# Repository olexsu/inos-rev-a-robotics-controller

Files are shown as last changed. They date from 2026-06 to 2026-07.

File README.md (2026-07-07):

# INOS Rev A 

INOS Rev A is a custom robotics controller developed as a dedicated real-time motion-control node for NVIDIA Jetson-based robotic systems.

The platform follows a distributed control architecture where the NVIDIA Jetson performs high-level functions such as computer vision, AI processing, motion planning, and operator interaction, while the INOS controller executes deterministic real-time functions including motion control, homing, safety monitoring, sensor processing, and hardware management.

The first implementation of the INOS platform is a six-axis robotic arm prototype utilizing stepper motors, external motor drivers, and inductive proximity sensors for joint homing and position reference.

---

# Project Overview

INOS is built around a simple principle:

**High-level intelligence belongs on the Jetson.
Real-time control belongs on dedicated embedded hardware.**

This separation allows the robotics platform to maintain deterministic motion control while leveraging the computational capabilities of NVIDIA Jetson hardware for future AI and machine vision applications.

## NVIDIA Jetson Responsibilities

* Computer vision
* AI processing
* Motion planning
* User interface
* Task execution logic

## INOS Controller Responsibilities

* Multi-axis motion control
* Homing routines
* Safety monitoring
* Sensor processing
* CAN communication
* Hardware management

---

# Hardware Features

* Teensy 4.1 real-time controller
* CAN bus communication with NVIDIA Jetson
* 24V industrial power architecture
* Six-axis robotic arm support
* External STEP/DIR motor driver architecture
* Inductive proximity sensor integration
* Joint homing and position reference system
* Custom 4-layer PCB designed in KiCad
* Modular expansion architecture

---

# System Architecture

```text
Controller / Vision System
            │
            ▼
     NVIDIA Jetson
   (High-Level Control)
            │
         CAN Bus
            │
            ▼
        INOS Rev A
 (Real-Time Controller)
            │
        STEP / DIR
            │
            ▼
 External Driver Board
            │
            ▼
     Stepper Motors
            │
            ▼
 Inductive Homing Sensors
```

---

# Homing and Position Reference

One of the core functions of INOS Rev A is establishing known joint positions after power-up.

Because stepper motors do not inherently know their absolute position when the system starts, each robotic axis uses an inductive proximity sensor as a mechanical reference point.

During initialization:

1. The controller moves each joint toward its reference position.
2. The inductive sensor detects the target.
3. The controller records the reference position.
4. The robot establishes a known coordinate system for all subsequent motion.

This homing architecture allows repeatable positioning and forms the foundation for future inverse kinematics, trajectory planning, and autonomous operation.

---

# Custom Controller Hardware

## Partly Assembled Controller Board — Top

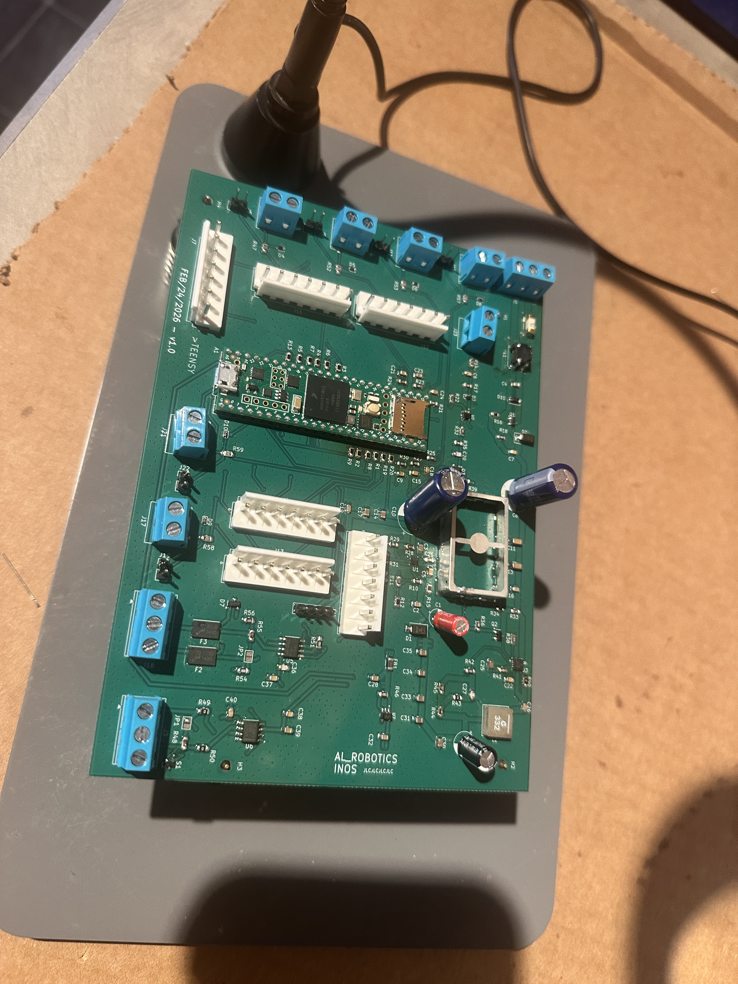
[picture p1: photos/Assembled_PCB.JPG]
INOS Rev A Board Bottom


Features:

* Custom 4-layer PCB
* Teensy 4.1 controller
* CAN transceiver
* Sensor interfaces
* Motion-control interfaces
* 24V power architecture
* Expansion capability

---

# PCB Design

## 3D Render

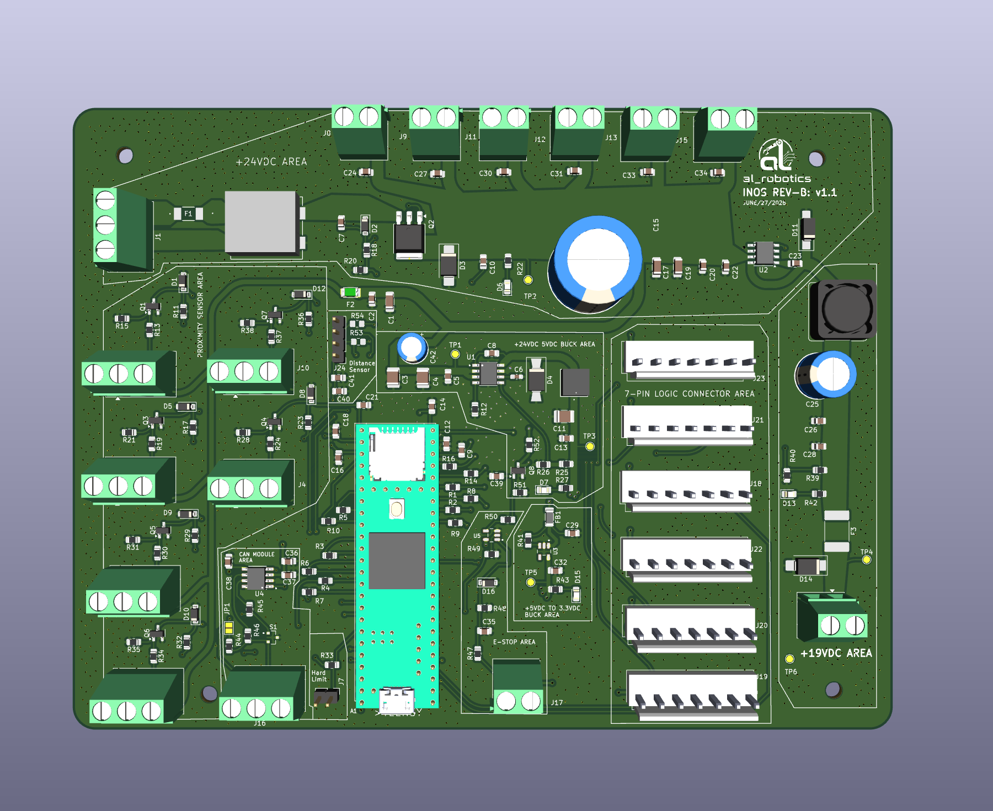
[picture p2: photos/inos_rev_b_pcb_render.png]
3D Render


Designed using KiCad and manufactured through JLCPCB.

---

# Development and Validation

## Power-On Testing

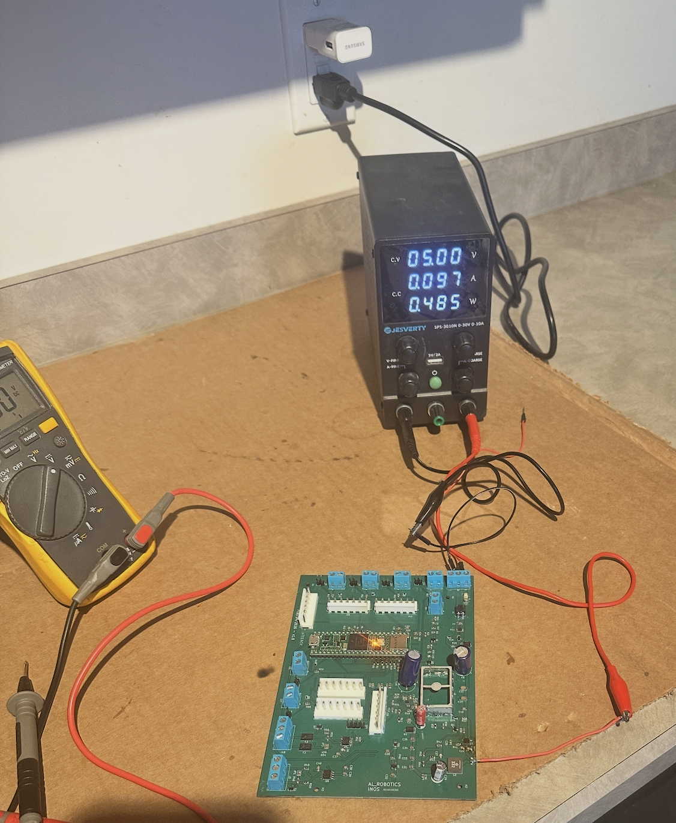
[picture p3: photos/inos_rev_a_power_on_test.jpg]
Power-On Testing


## CAN Communication Testing

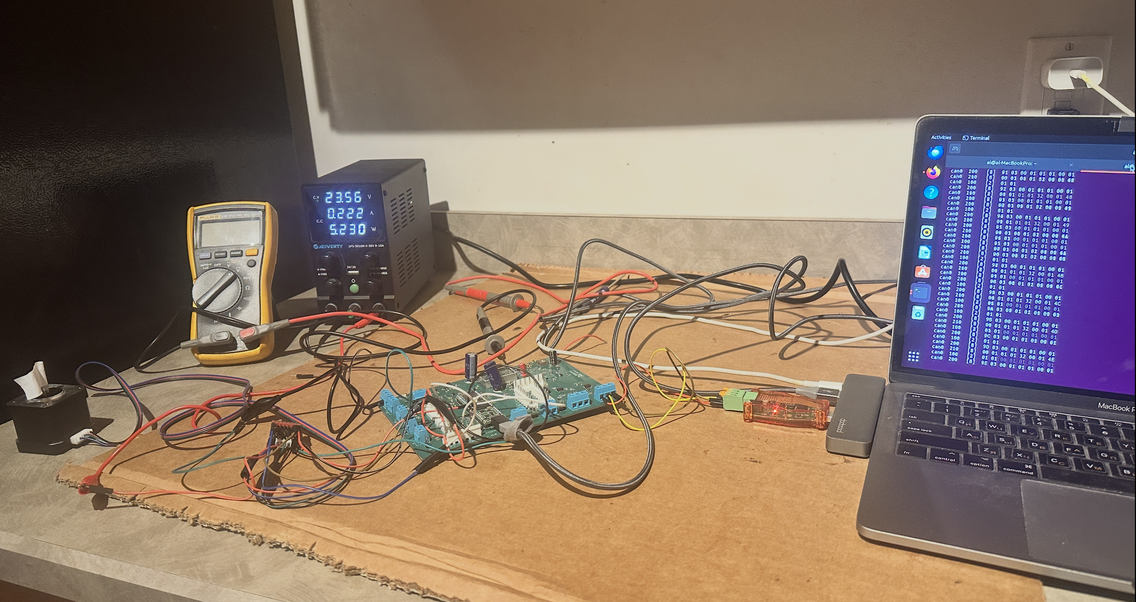
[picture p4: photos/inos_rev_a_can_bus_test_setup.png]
CAN Bus Testing


The INOS Rev A platform has successfully demonstrated:

* Controller board bring-up
* CAN communication
* Multi-axis motion control
* Inductive sensor integration
* Joint homing
* Robotic arm operation
* Embedded firmware validation

---

# Current Status

## Completed

* Custom PCB design
* PCB manufacturing and assembly
* Teensy 4.1 integration
* CAN communication testing
* Multi-axis motion control
* Inductive homing implementation
* Robotic arm prototype integration

## In Progress

* Motion-control refinement
* Safety system development
* CAN protocol expansion
* System optimization

## Planned

* NVIDIA Jetson integration
* Computer vision
* Inverse kinematics
* Autonomous operation
* Agricultural robotics applications

---

# Project Goals

The long-term objective of the INOS platform is to create a scalable robotics architecture capable of supporting:

* Robotic manipulators
* Agricultural automation systems
* Machine vision platforms
* Autonomous robotic applications
* Custom embedded robotics solutions

---

# Development Tools

* KiCad
* Teensy 4.1
* C++
* FlexCAN_T4
* NVIDIA Jetson
* Ubuntu Linux
* GitHub
* JLCPCB

---

# Disclaimer

INOS Rev A is an experimental development platform and active engineering project. The hardware and software are continuously evolving as new features, capabilities, and lessons learned are incorporated into future revisions.

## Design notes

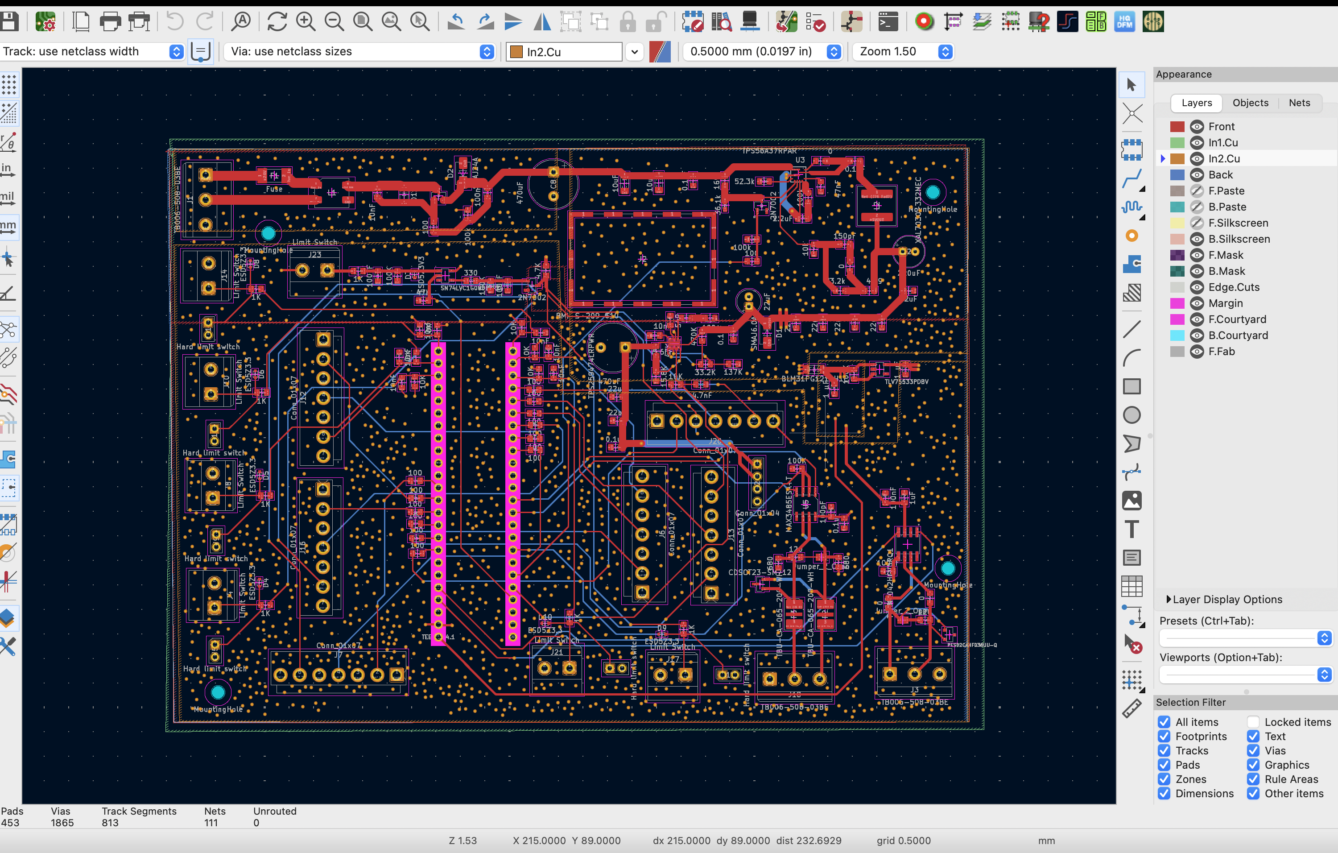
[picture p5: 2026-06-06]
photos/inos_rev_a_pcb_layout.png

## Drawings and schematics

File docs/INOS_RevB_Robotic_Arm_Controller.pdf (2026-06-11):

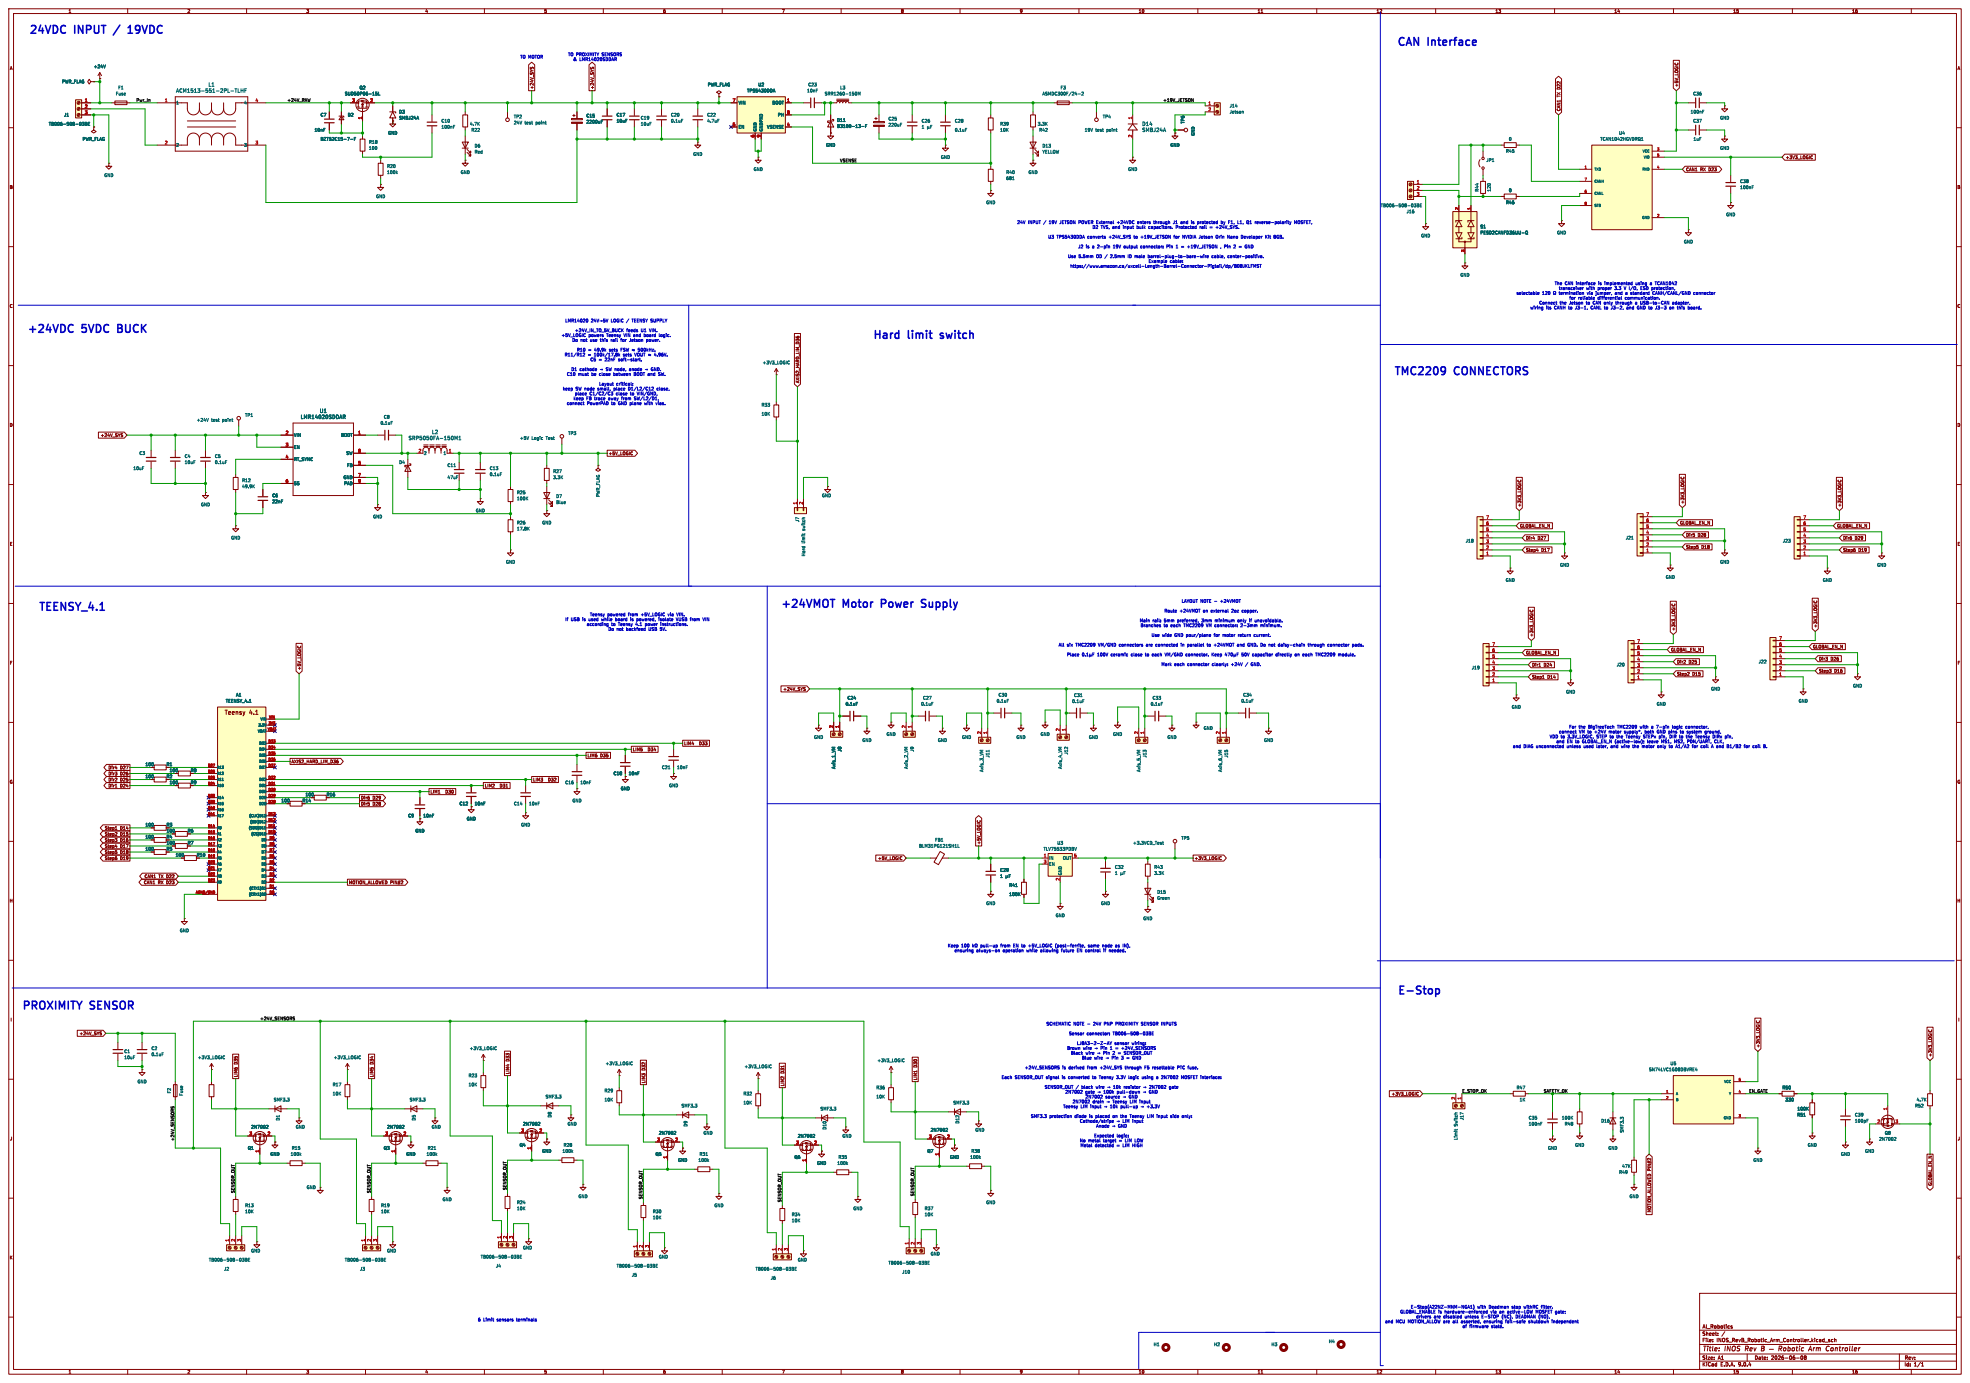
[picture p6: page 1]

Example cable: https://www.amazon.ca/uxcell-Length-Barrel-Connector-Pigtail/dp/B08JKLFMST

LMR14020 þÿ24V!’5VLOGIC / TEENSY SUPPLY

Teensy powered from +5V_LOGIC via VIN.

If USB is used while board is powered, isolate VUSB from VIN

SCHEMATIC NOTE - 24V PNP PROXIMITY SENSOR INPUTS

Black wire þÿ!’Pin 2 = SENSOR_OUT Blue wire þÿ!’Pin 3 = GND

2N7002 source þÿ!’GND
2N7002 drain þÿ!’Teensy LIM input

Expected logic: No metal target = LIM LOW

Id: 1/1 Title: INOS Rev B þÿ Robotic Arm Controller File: INOS_RevB_Robotic_Arm_Controller.kicad_sch Sheet: / Al_Robotics

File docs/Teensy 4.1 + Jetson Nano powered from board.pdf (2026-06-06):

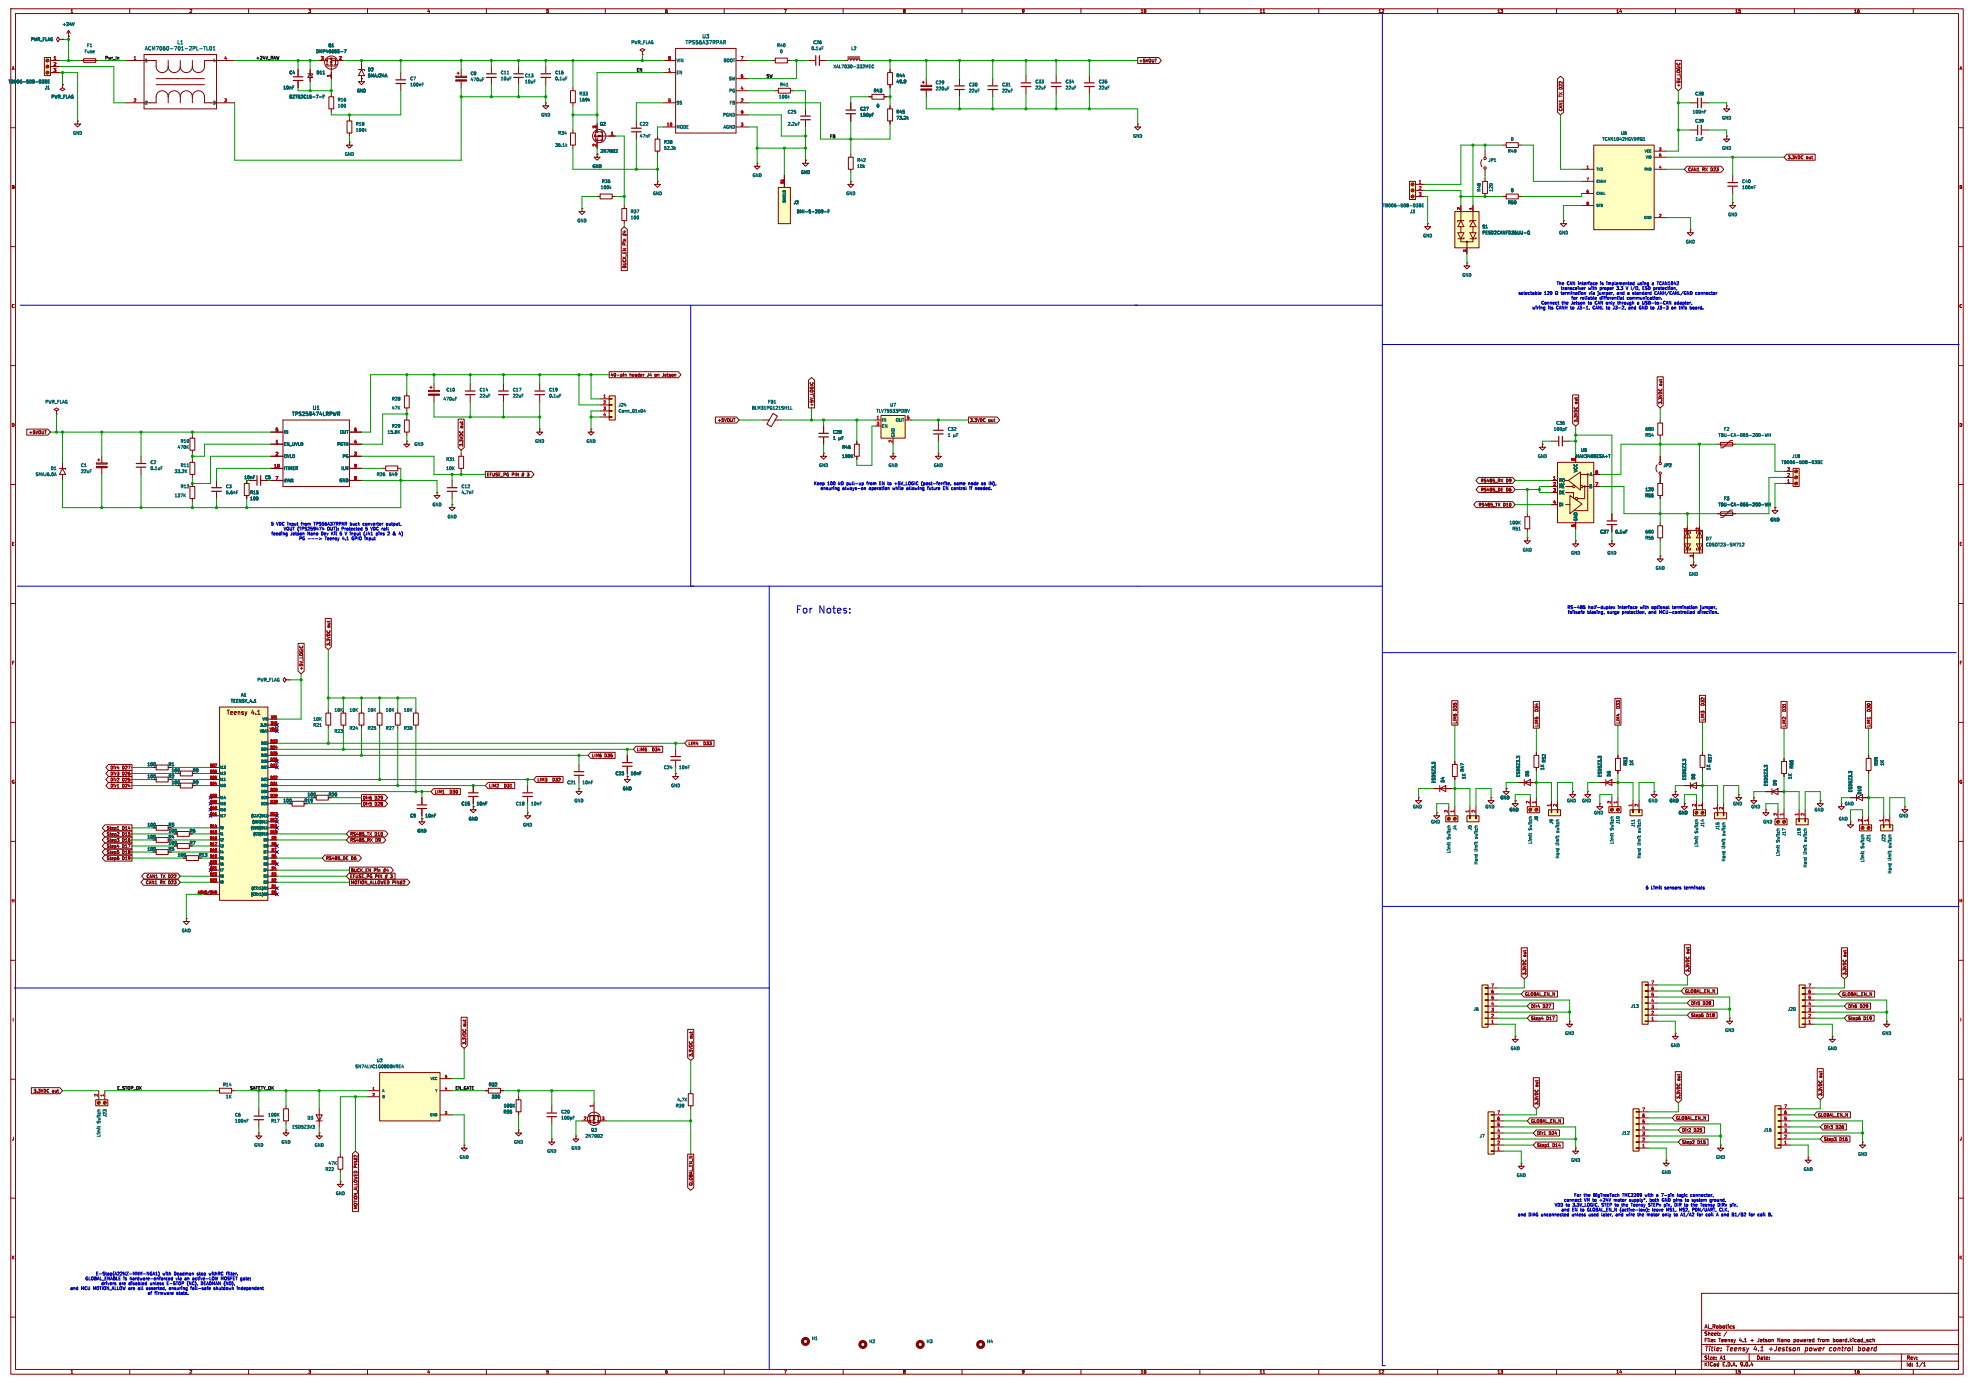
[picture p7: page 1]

1 J17 Limit Switch F3 TBU-CA-065-200-WH

Id: 1/1 Title: Teensy 4.1 +Jestson power control board

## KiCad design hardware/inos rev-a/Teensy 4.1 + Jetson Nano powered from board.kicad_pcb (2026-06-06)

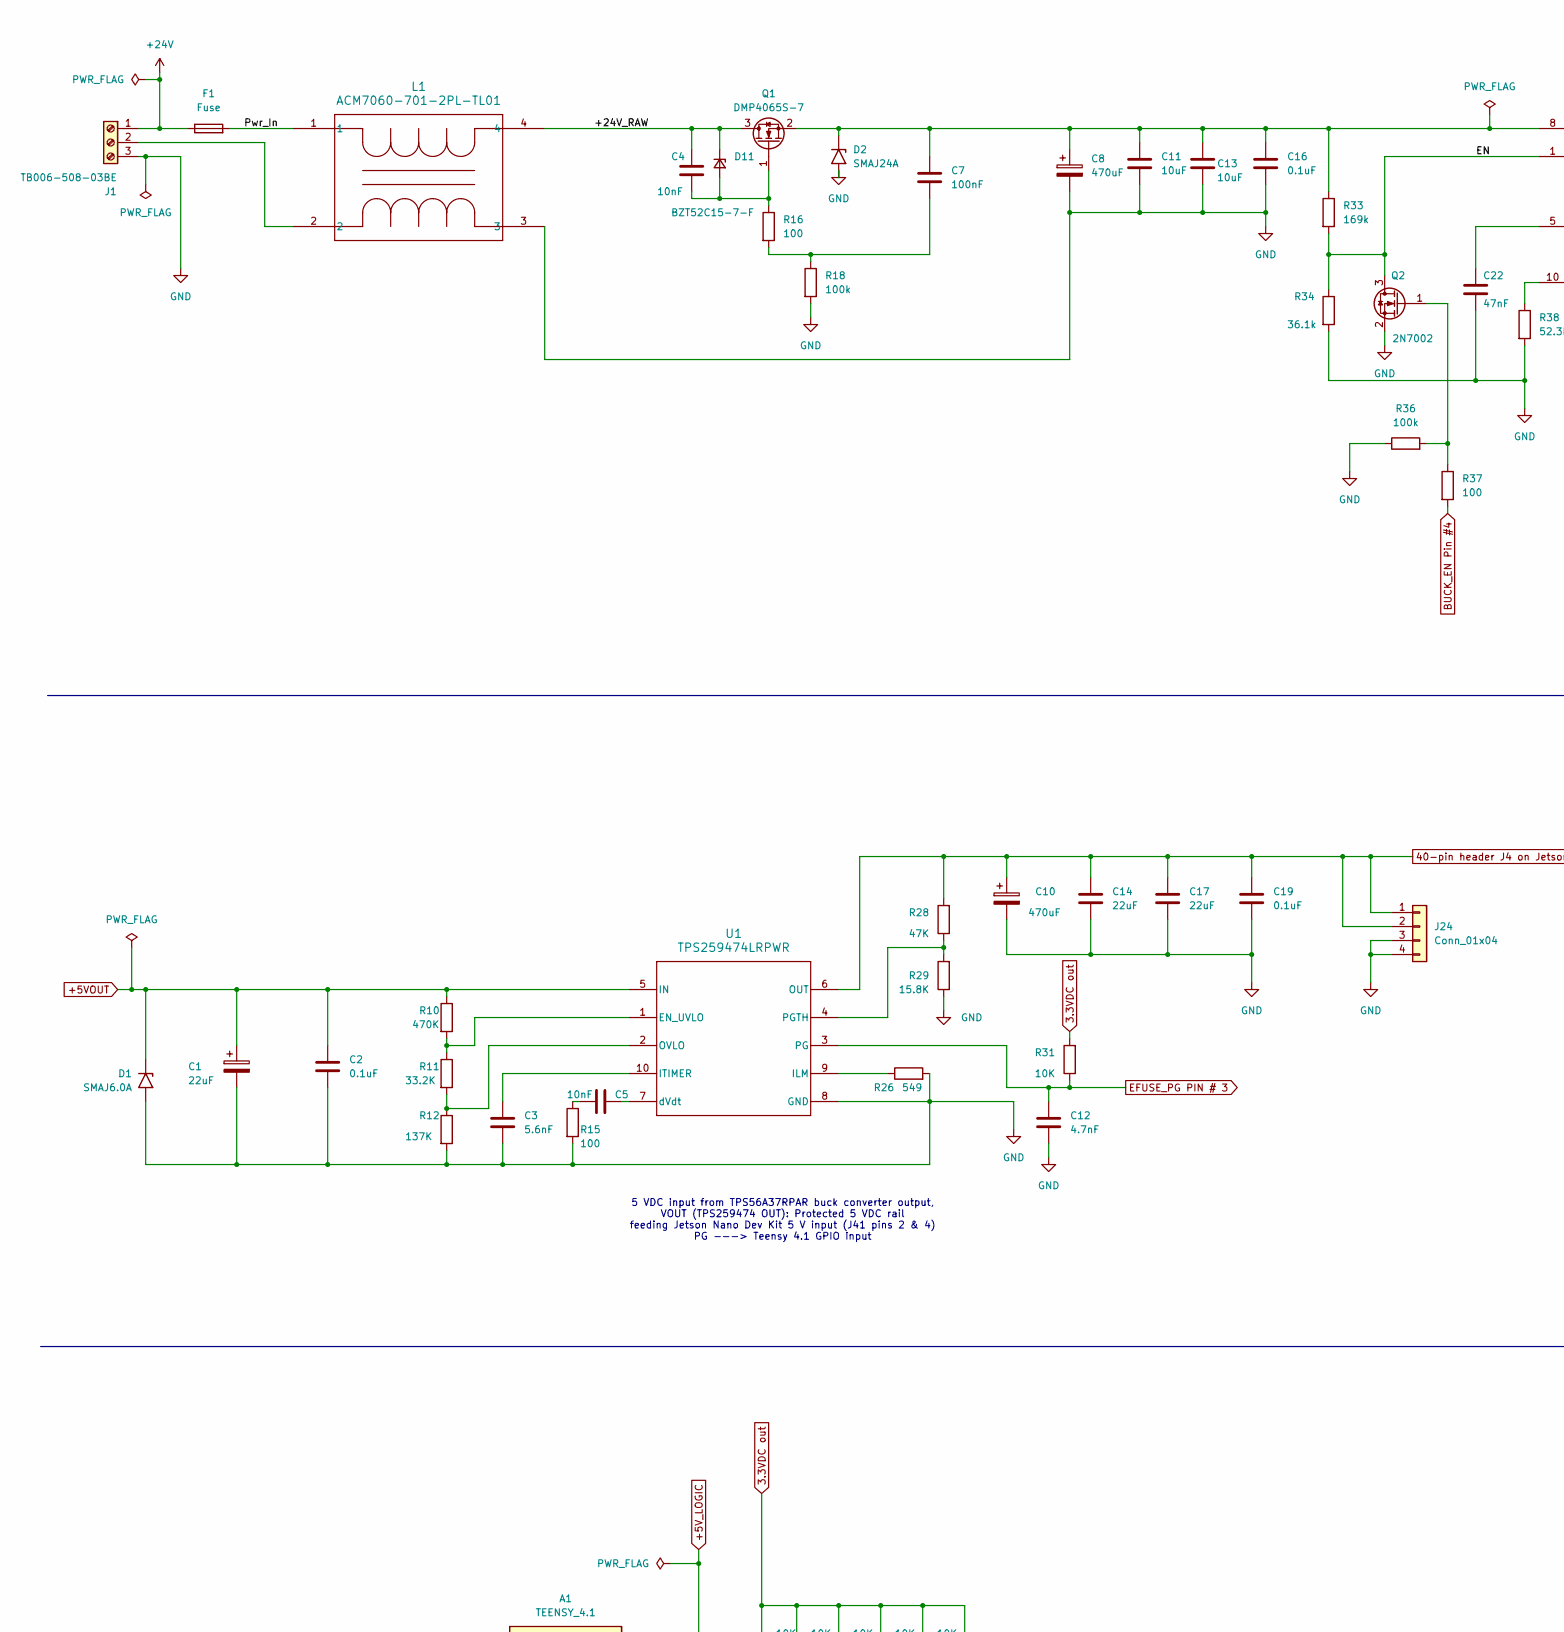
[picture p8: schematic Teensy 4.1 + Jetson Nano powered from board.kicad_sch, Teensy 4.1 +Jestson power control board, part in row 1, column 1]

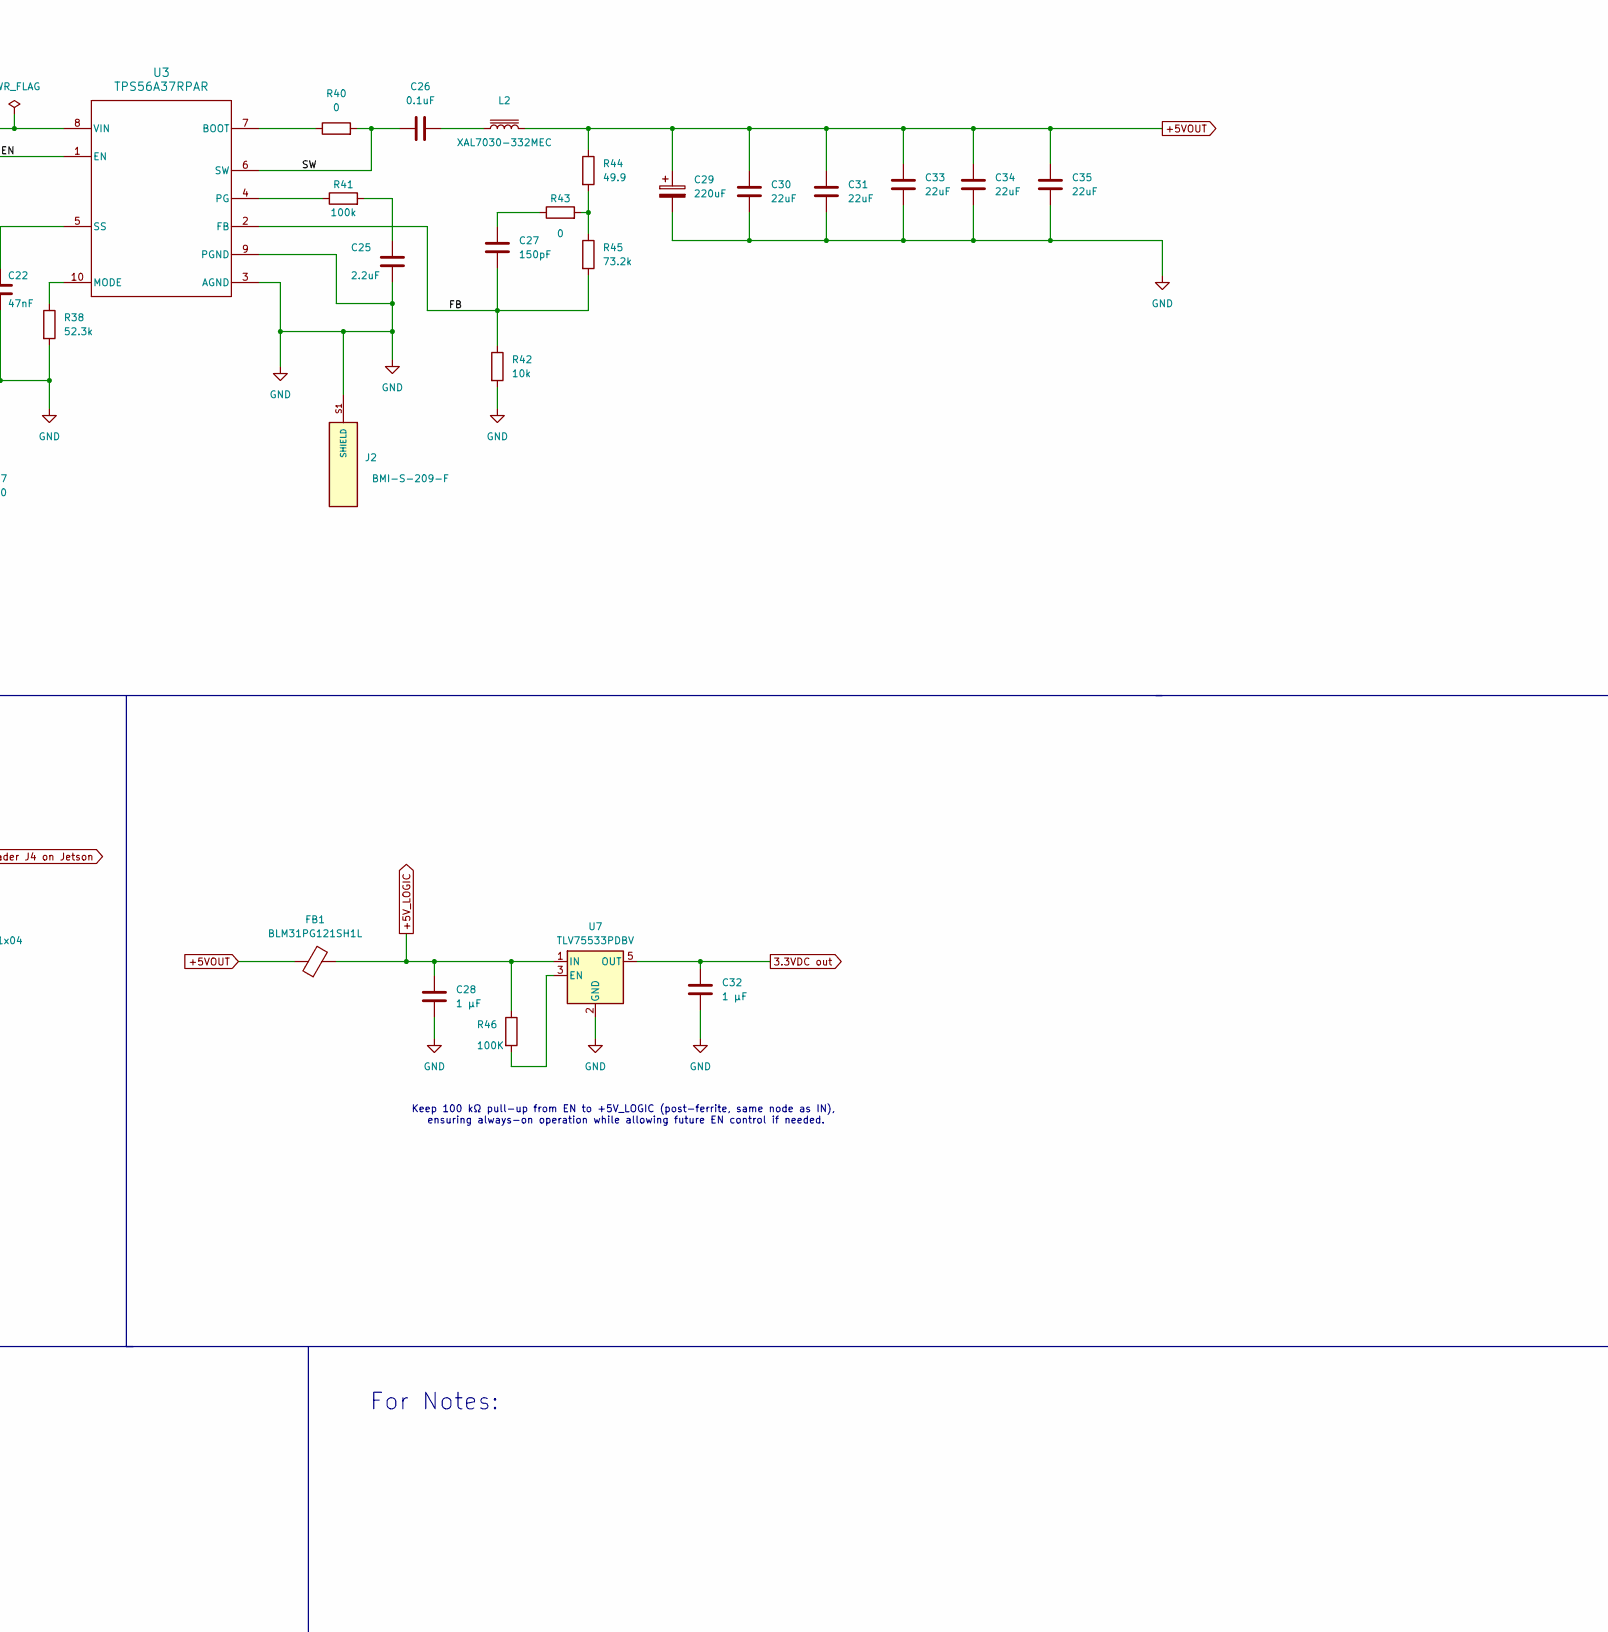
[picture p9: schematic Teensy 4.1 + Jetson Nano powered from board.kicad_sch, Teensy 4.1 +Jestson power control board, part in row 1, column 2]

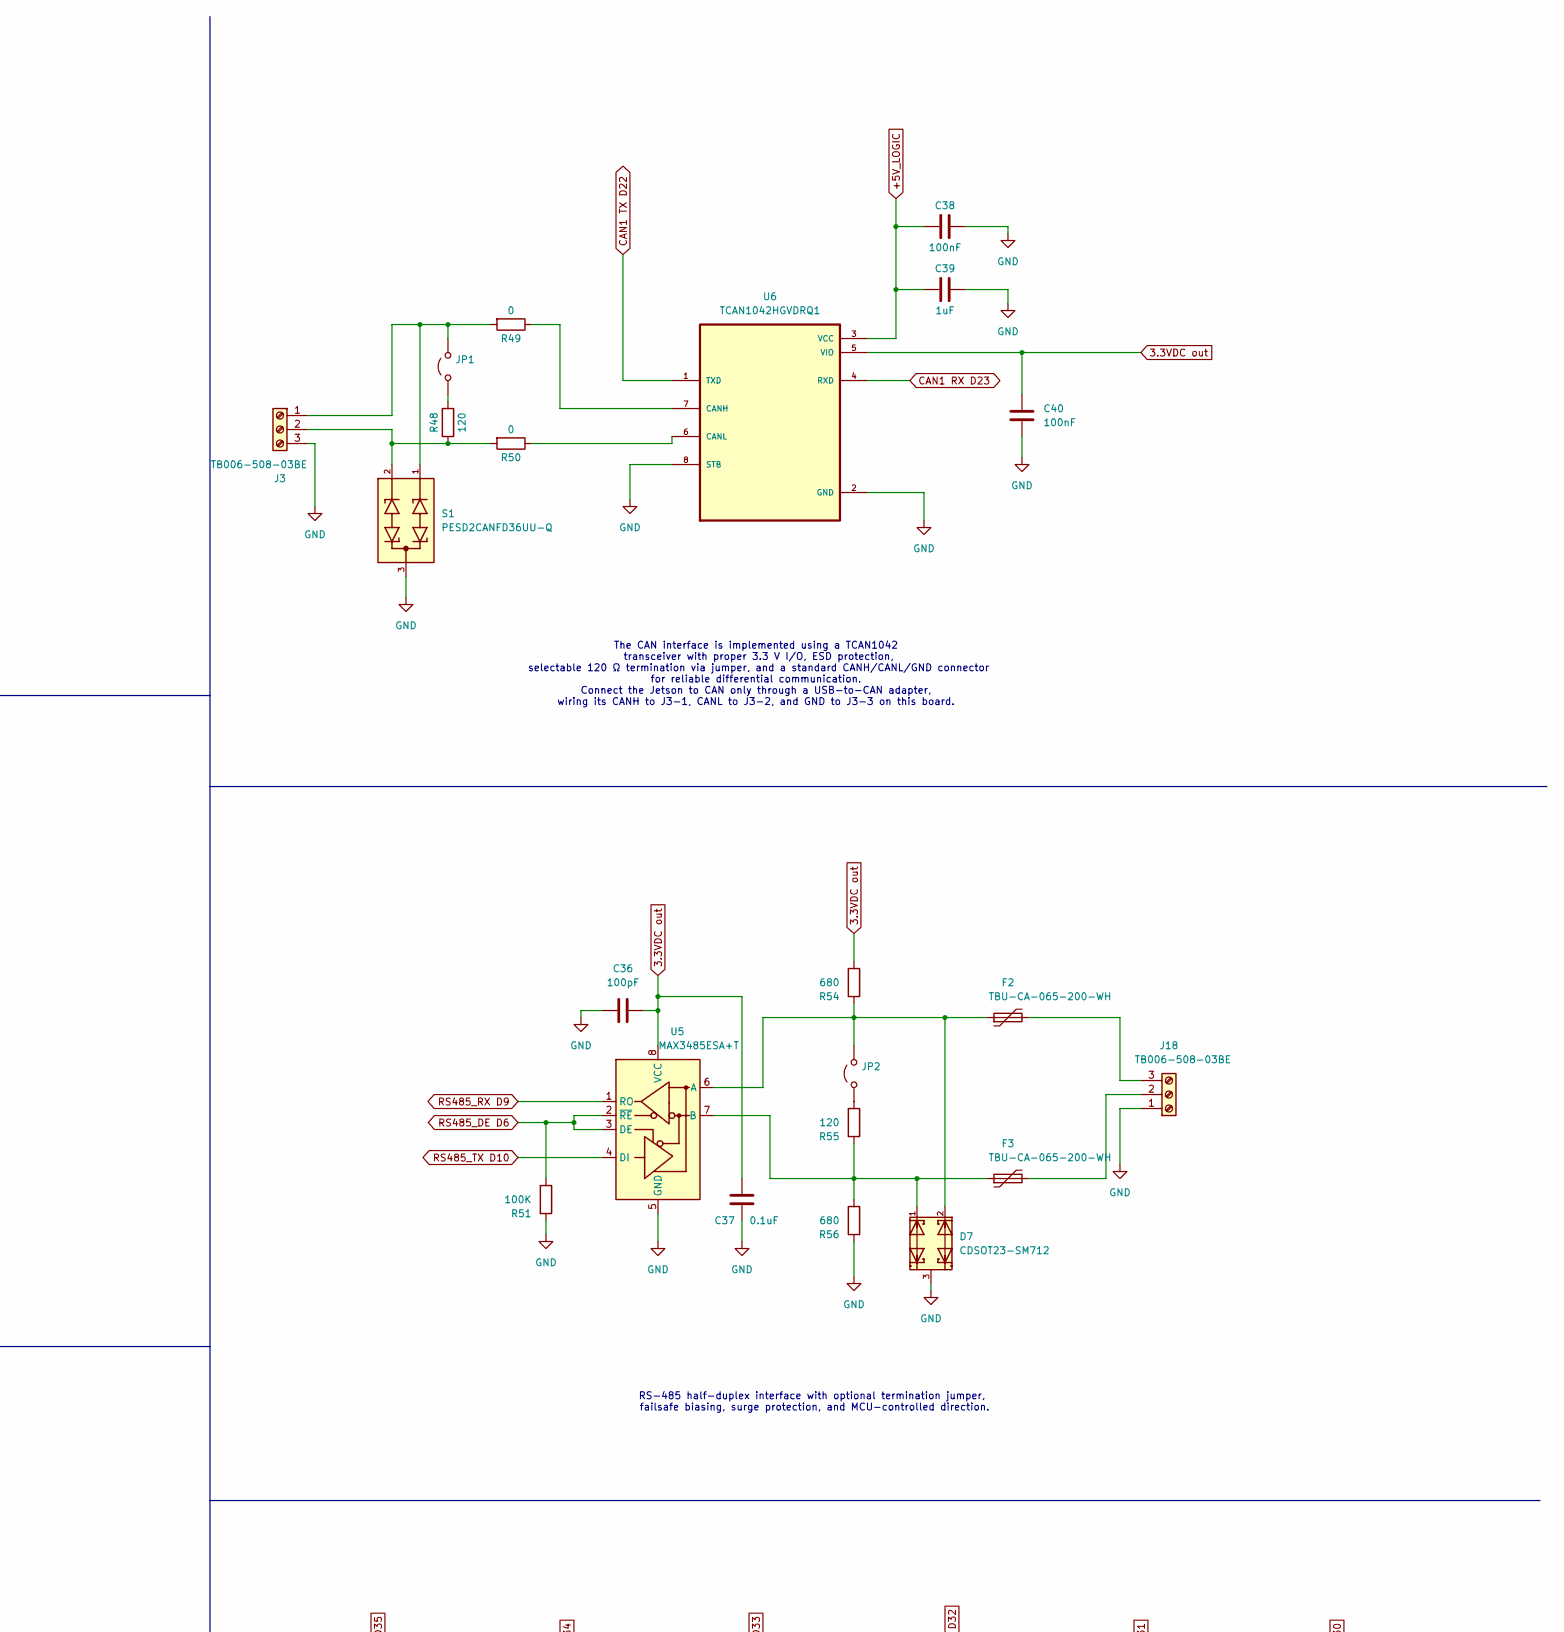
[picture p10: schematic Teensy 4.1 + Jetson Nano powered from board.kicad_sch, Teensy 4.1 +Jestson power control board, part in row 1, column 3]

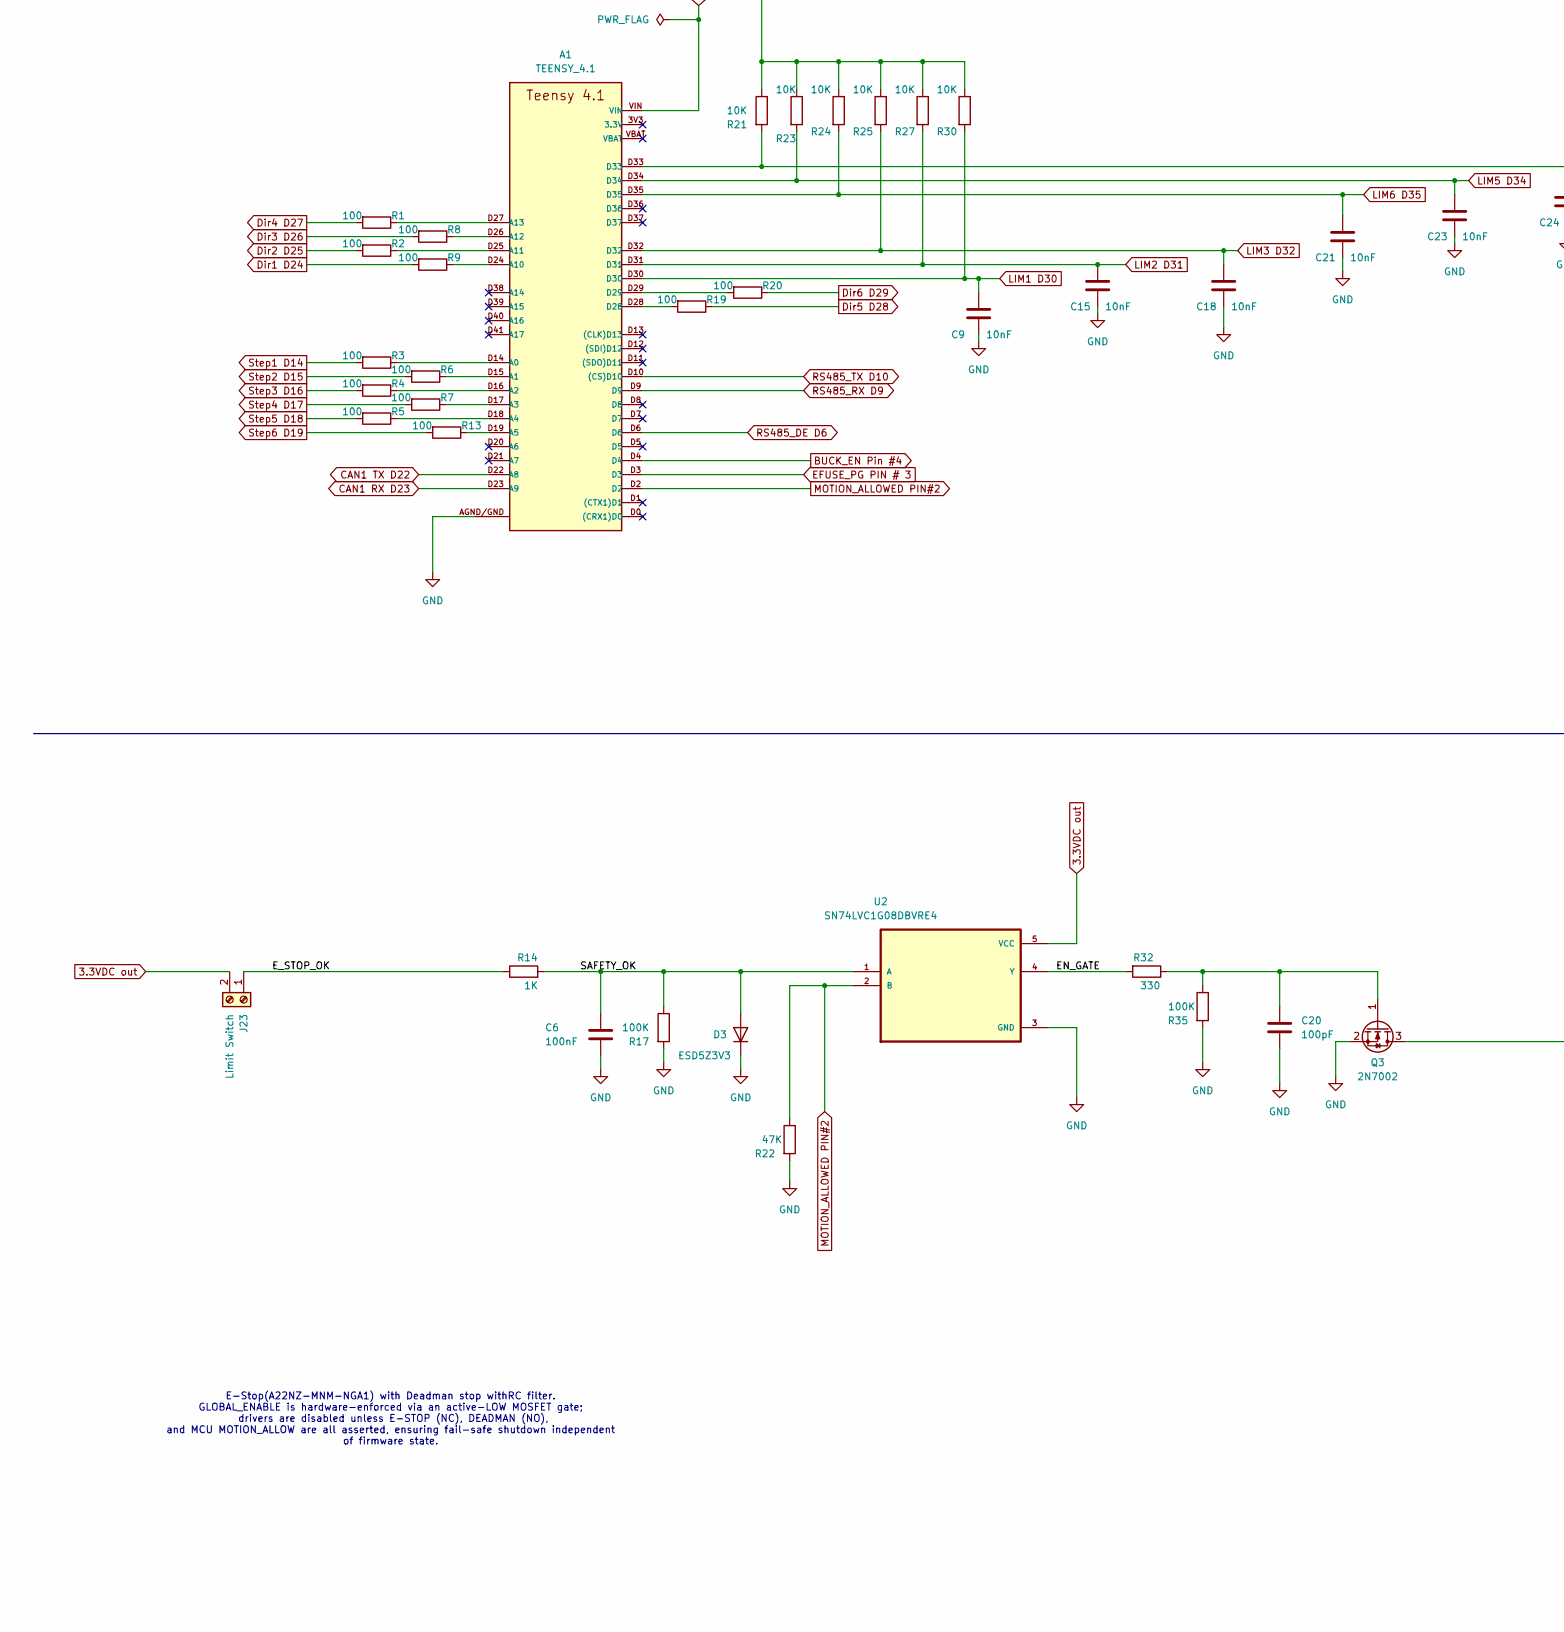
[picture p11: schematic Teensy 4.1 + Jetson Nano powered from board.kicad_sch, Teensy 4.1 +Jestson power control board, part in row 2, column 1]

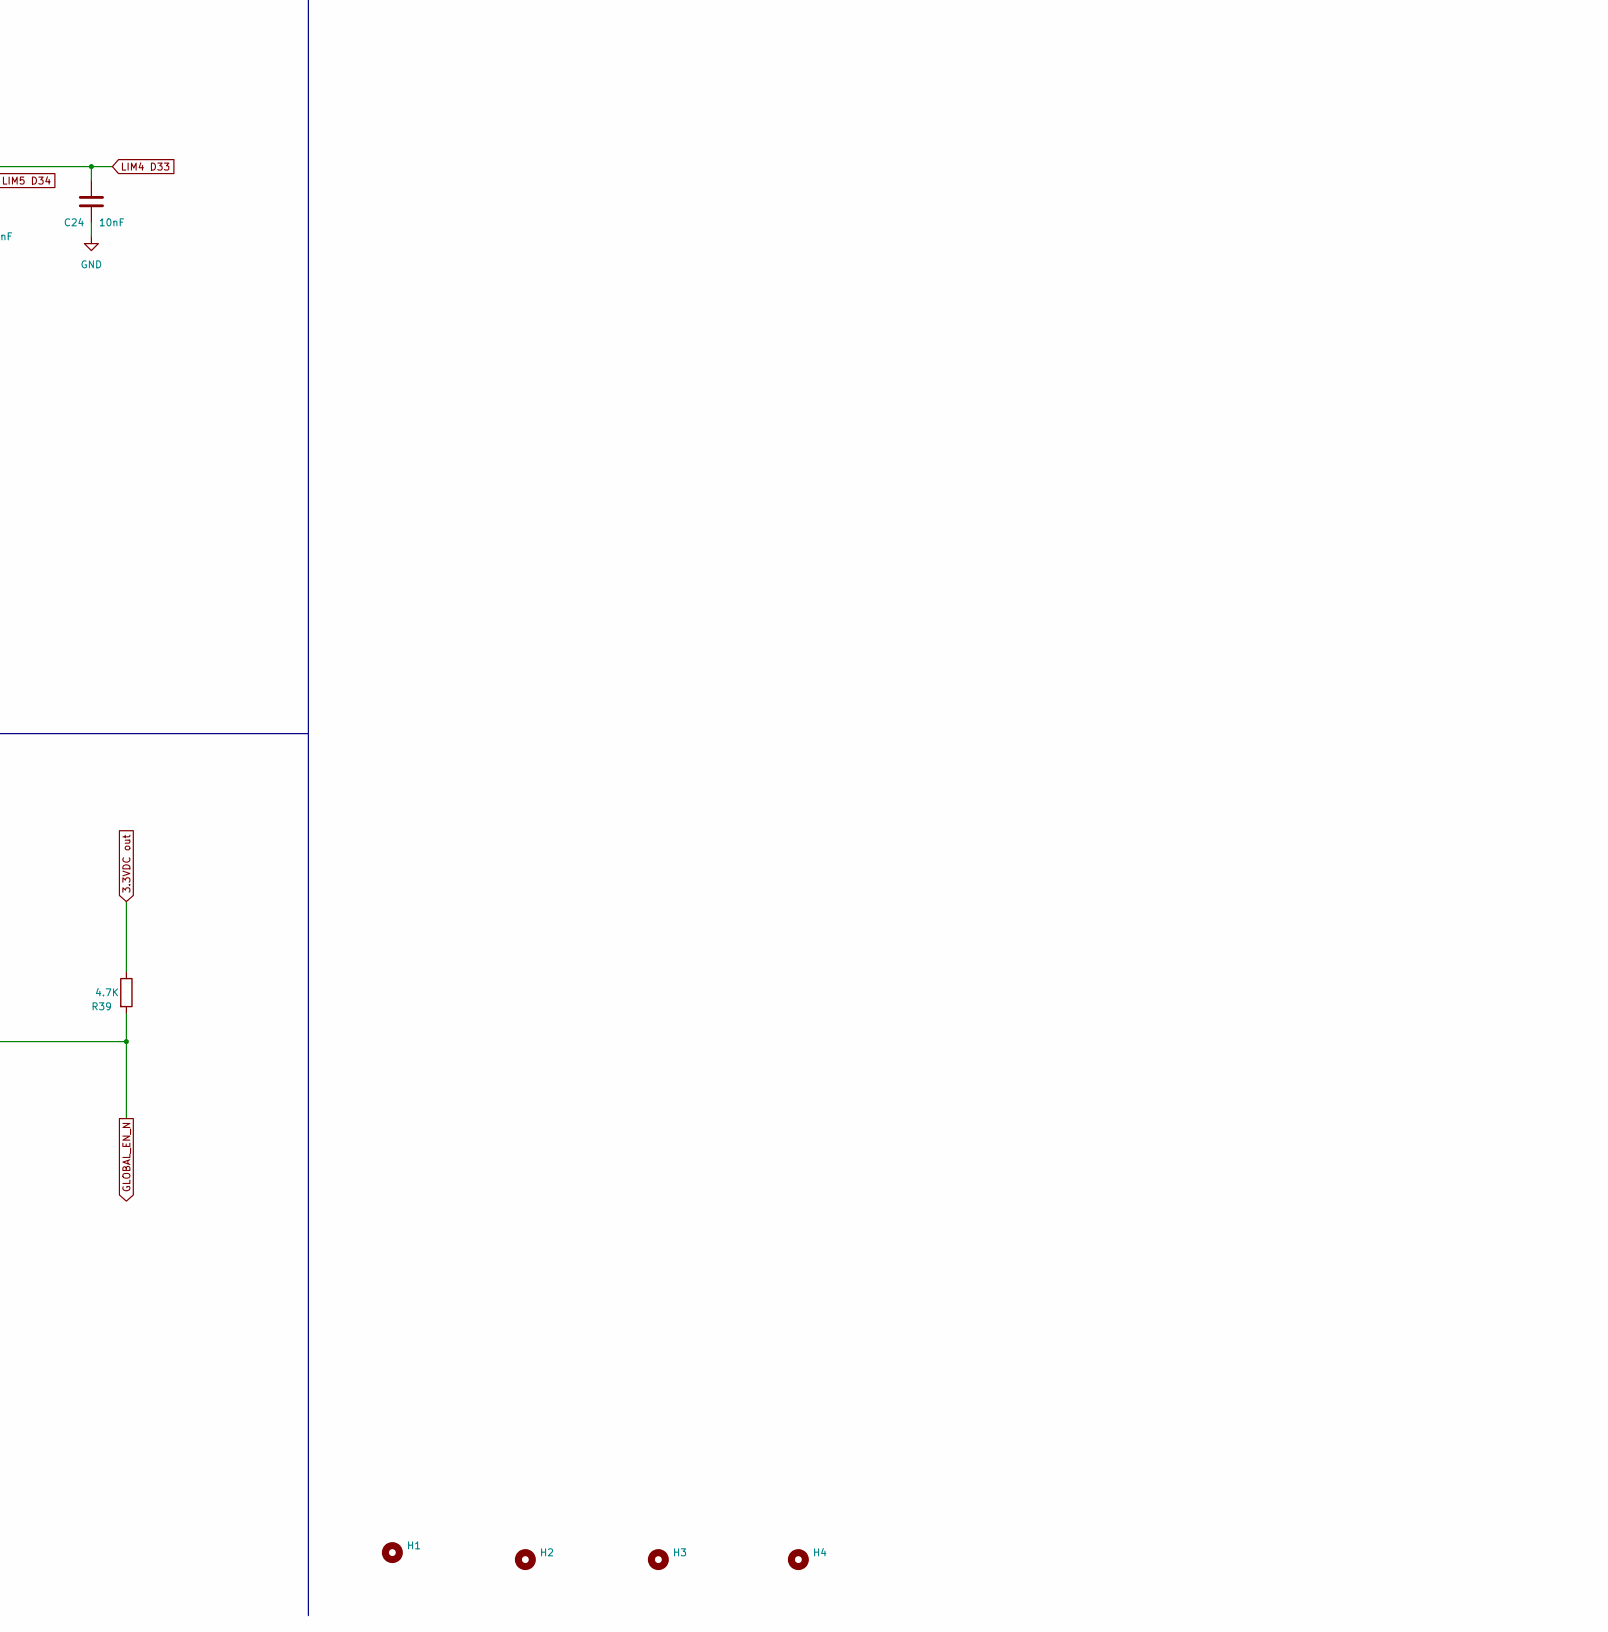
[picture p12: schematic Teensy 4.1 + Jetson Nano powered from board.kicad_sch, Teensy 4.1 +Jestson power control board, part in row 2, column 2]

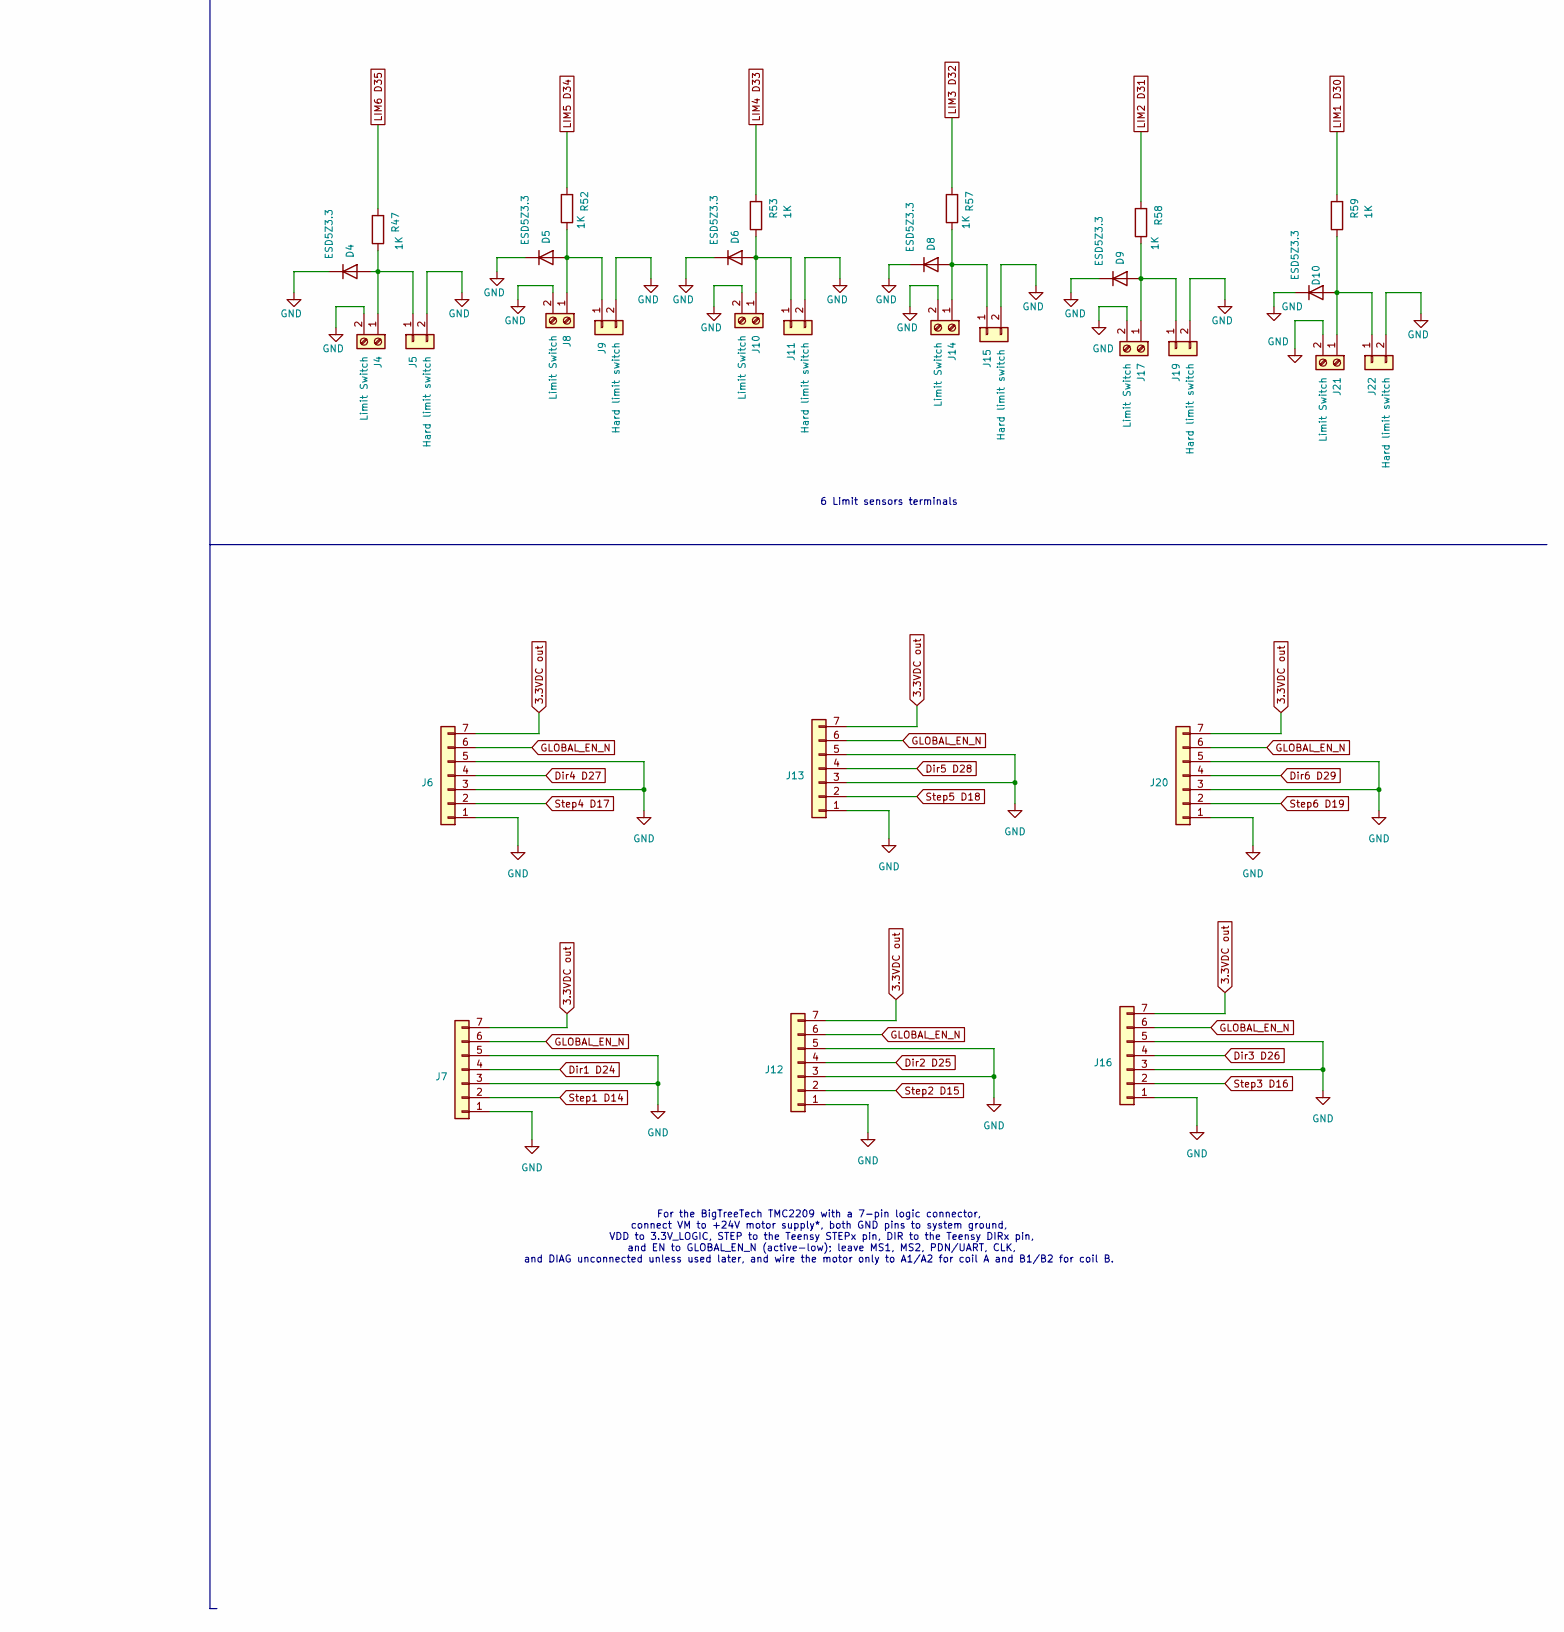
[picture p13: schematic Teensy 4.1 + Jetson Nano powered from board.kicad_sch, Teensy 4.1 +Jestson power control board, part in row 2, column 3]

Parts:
A1: TEENSY_4.1; TEENSY_LONG_EXT
C1: 22uF; CP_Radial_D5.0mm_P2.00mm; Manufacturer # 860010472003
C2, C16, C19, C26, C37: 0.1uF; C_0805_2012Metric_Pad1.18x1.45mm_HandSolder; Manufacturer # C0805C104K5RACTU
C3: 5.6nF; C_0805_2012Metric_Pad1.18x1.45mm_HandSolder; Manufacturer # C0805C562K4HACAUTO
C4: 10nF; R_0805_2012Metric_Pad1.20x1.40mm_HandSolder; Manufacturer # C0805C103K5RACTU
C5, C9, C15, C18, C21, C23, C24: 10nF; C_0805_2012Metric_Pad1.18x1.45mm_HandSolder; Manufacturer # C0805C103K5RACTU
C6, C7, C38, C40: 100nF; C_0805_2012Metric_Pad1.18x1.45mm_HandSolder; Manufacturer # KGM21NR71E104KT
C8, C10: 470uF; CP_Radial_D10.0mm_P5.00mm; Manufacturer # ECA-1HM471
C11, C13: 10uF; C_1206_3216Metric_Pad1.33x1.80mm_HandSolder; Manufacturer # CL31A106KBHNNNE
C12: 4.7nF; C_0805_2012Metric_Pad1.18x1.45mm_HandSolder; Manufacturer # KGM05AR71E472KH
C14, C17, C30, C31, C33, C34, C35: 22uF; C_0805_2012Metric_Pad1.18x1.45mm_HandSolder; Manufacturer # CL21A226MAYNNNE
C20, C36: 100pF; C_0805_2012Metric_Pad1.18x1.45mm_HandSolder; Manufacturer # CC0805KRX7R8BB101
C22: 47nF; C_0805_2012Metric_Pad1.18x1.45mm_HandSolder; Manufacturer # CL21B473KBCNNNC
C25: 2.2uF; C_0805_2012Metric_Pad1.18x1.45mm_HandSolder; Manufacturer # CL21A225KBFNNNE
C27: 150pF; C_0805_2012Metric_Pad1.18x1.45mm_HandSolder; Manufacturer # C0805C151J5GACTU
C28, C32: 1 µF; C_0805_2012Metric_Pad1.18x1.45mm_HandSolder; Manufacturer # CL21B105KAFNNNE
C29: 220uF; CP_Radial_D6.3mm_P2.50mm; Manufacturer # RET0611221M025B
C39: 1uF; C_0805_2012Metric_Pad1.18x1.45mm_HandSolder; Manufacturer # CL21B105KAFNNNE
D1: SMAJ6.0A; D_SMA; Manufacturer # SMAJ6.0A
D2: SMAJ24A; D_SMA; Manufacturer # SMAJ24A
D3: ESD5Z3V3; D_SOD-523; Manufacturer # ESD5Z3V3
D4, D5, D6, D8, D9, D10: ESD5Z3.3; D_SOD-523; Manufacturer # ESD5Z3V3
D7: CDSOT23-SM712; SOT-23; Manufacturer # CDSOT23-SM712
D11: BZT52C15-7-F; D_SOD-123; Manufacturer # BZT52C15-7-F
F1: Fuse; Fuse_Littelfuse-NANO2-451_453; Manufacturer # 0452005.MRL
F2, F3: TBU-CA-065-200-WH; Fuse_Bourns_TBU-CA; Manufacturer # TBU-CA065-200-WH
FB1: BLM31PG121SH1L; L_1206_3216Metric; Manufacturer # BLM31PG121SH1L
H1, H2, H3, H4: MountingHole; MountingHole_2.5mm
J1, J3, J18: TB006-508-03BE; TerminalBlock_Phoenix_MKDS-1,5-3-5.08_1x03_P5.08mm_Horizont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; Manufacturer # TB006-508-03BE
J2: BMI-S-209-F; Laird_Technologies_BMI-S-209-F_29.36x18.50mm; Manufacturer # BMI-S-209-F
J4, J8, J10, J14, J17, J21, J23: Limit Switch; TerminalBlock_Phoenix_MKDS-1,5-2-5.08_1x02_P5.08mm_Horizont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; Manufacturer # TB006-508-02BE
J5, J9, J11, J15, J19, J22: Hard limit switch; PinHeader_1x02_P2.54mm_Vertical; Manufacturer # CONN HEADER VERT 2POS 2.54MM
J6, J7, J12, J13, J16, J20: Conn_01x07; JST_VH_B7P-VH-B_1x07_P3.96mm_Vertical; Manufacturer # B7P-VH-B
J24: Conn_01x04; PinHeader_1x04_P2.54mm_Vertical; Manufacturer # PH1-04-UA
JP1, JP2: Jumper_2_Open; SolderJumper-2_P1.3mm_Open_Pad1.0x1.5mm
L1: ACM7060-701-2PL-TL01; L_CommonModeChoke_TDK_ACM7060; Manufacturer # ACM7060-701-2PL-TL01
L2: XAL7030-332MEC; L_Coilcraft_XAL7030-332; Manufacturer # XAL7030-332MEC
Q1: DMP4065S-7; SOT-23; Manufacturer # DMP4065S-7
Q2, Q3: 2N7002; SOT-23-3; Manufacturer # MOSFET N-CH 60V 280MA SOT23-3
R1, R2, R3, R4, R5, R6, R7, R8, R9, R13, R15, R16, R19, R20, R37: 100; R_0805_2012Metric_Pad1.20x1.40mm_HandSolder; Manufacturer # CRCW0805100RFKEA
R10: 470K; R_0805_2012Metric_Pad1.20x1.40mm_HandSolder; Manufacturer # RC0805FR-07470KL
R11: 33.2K; R_0805_2012Metric_Pad1.20x1.40mm_HandSolder; Manufacturer # RMCF0805FT33K2
R12: 137K; R_0805_2012Metric_Pad1.20x1.40mm_HandSolder; Manufacturer # CRCW0805137KFKEA
R14, R47, R52, R53, R57, R58, R59: 1K; R_0805_2012Metric_Pad1.20x1.40mm_HandSolder; Manufacturer # RR1220P-102-D
R17, R35, R46, R51: 100K; R_0805_2012Metric_Pad1.20x1.40mm_HandSolder; Manufacturer # RC0805FR-07100KL
R18, R36, R41: 100k; R_0805_2012Metric_Pad1.20x1.40mm_HandSolder; Manufacturer # RC0805FR-07100KL
R21, R23, R24, R25, R27, R30, R31: 10K; R_0805_2012Metric_Pad1.20x1.40mm_HandSolder; Manufacturer # RC0805JR-0710KL
R22, R28: 47K; R_0805_2012Metric_Pad1.20x1.40mm_HandSolder; Manufacturer # RMCF0805JT47K0
R26: 549; R_0805_2012Metric_Pad1.20x1.40mm_HandSolder; Manufacturer # RC0805FR-07549RL
R29: 15.8K; R_0805_2012Metric_Pad1.20x1.40mm_HandSolder; Manufacturer # RC0805FR-0715K8L
R32: 330; R_0805_2012Metric_Pad1.20x1.40mm_HandSolder; Manufacturer # RC0805FR-07330RL
R33: 169k; R_0805_2012Metric_Pad1.20x1.40mm_HandSolder; Manufacturer # RMCF0805FT169K
R34: 36.1k; R_0603_1608Metric_Pad0.98x0.95mm_HandSolder; Manufacturer # RN73R1JTTD3612F100
R38: 52.3k; R_0805_2012Metric_Pad1.20x1.40mm_HandSolder; Manufacturer # RC0805FR-0752K3L
R39: 4.7K; R_0805_2012Metric_Pad1.20x1.40mm_HandSolder; Manufacturer # ERA-6AEB472V
R40, R43, R49, R50: 0; R_0805_2012Metric_Pad1.20x1.40mm_HandSolder; Manufacturer # RC0805JR-070RL
R42: 10k; R_0805_2012Metric_Pad1.20x1.40mm_HandSolder; Manufacturer # RC0805JR-0710KL
R44: 49.9; R_0805_2012Metric_Pad1.20x1.40mm_HandSolder; Manufacturer # RMCF0805FT49R9
R45: 73.2k; R_0805_2012Metric_Pad1.20x1.40mm_HandSolder; Manufacturer # RC0805FR-0773K2L
R48, R55: 120; R_0805_2012Metric_Pad1.20x1.40mm_HandSolder; Manufacturer # RMCF0805FT120R
R54, R56: 680; R_0805_2012Metric_Pad1.20x1.40mm_HandSolder; Manufacturer # RMCF0805FT680R
S1: PESD2CANFD36UU-Q; DIO_PESD2CAN_215; Manufacturer # PESD2CANFD36UU-QF
U1: TPS259474LRPWR; IC_TPS25974ARPWR; Manufacturer # TPS259474LRPWR
U2: SN74LVC1G08DBVRE4; SOT95P280X145-5N; Manufacturer # SN74LVC1G08DBVRE4
U3: TPS56A37RPAR; RPA0010A-MFG; Manufacturer # TPS56A37RPAR
U5: MAX3485ESA+T; SOIC-8_3.9x4.9mm_P1.27mm; Manufacturer # MAX3485ESA+
U6: TCAN1042HGVDRQ1; Manufacturer # TCAN1042HGVDRQ1
U7: TLV75533PDBV; Manufacturer # TLV75533PDBVR

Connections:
3.3VDC out: C32.1, C36.2, C37.1, C40.1, J6.7, J7.7, J12.7, J13.7, J16.7, J20.7, J23.2, R21.1, R23.1, R24.1, R25.1, R27.1, R30.1, R31.2, R39.1, R54.1, U2.5 (VCC), U5.8 (VCC), U6.5 (VIO), U7.5 (OUT)
40-pin header J4 on Jetson: C10.1, C14.1, C17.1, C19.1, J24.1, J24.2, R28.2, U1.6 (OUT)
+5VOUT: C1.1, C2.1, C29.1, C30.1, C31.1, C33.1, C34.1, C35.1, D1.1 (A1), FB1.1, L2.2, R10.1, R44.1, U1.5 (IN)
+5V_LOGIC: A1.VIN, C28.1, C38.1, C39.1, FB1.2, R46.1, U6.3 (VCC), U7.1 (IN)
+24V: F1.1, J1.1
/+24V_RAW: C4.1, D11.1 (K), L1.4, Q1.3 (D)
/EN: Q2.3 (D), R33.2, R34.1, U3.1 (EN)
/EN_GATE: R32.2, U2.4 (Y)
/E_STOP_OK: J23.1, R14.1
/FB: C27.2, R42.1, R45.2, U3.2 (FB)
/Pwr_In: F1.2, L1.1
/SAFETY_OK: C6.1, D3.2 (A), R14.2, R17.1, U2.1 (A)
/SW: C26.1, R40.2, U3.6 (SW)
BUCK_EN Pin #4: A1.D4, R37.2
CAN1 RX D23: A1.D23 (A9), U6.4 (RXD)
CAN1 TX D22: A1.D22 (A8), U6.1 (TXD)
Dir1 D24: J7.4, R9.2
Dir2 D25: J12.4, R2.2
Dir3 D26: J16.4, R8.2
Dir4 D27: J6.4, R1.2
Dir5 D28: J13.4, R19.1
Dir6 D29: J20.4, R20.1
EFUSE_PG PIN # 3: A1.D3, C12.1, R31.1, U1.3 (PG)
GLOBAL_EN_N: J6.6, J7.6, J12.6, J13.6, J16.6, J20.6, Q3.3 (D), R39.2
GND: A1.AGND/GND, C1.2, C2.2, C3.2, C6.2, C8.2, C9.2, C10.2, C11.2, C12.2, C13.2, C14.2, C15.2, C16.2, C17.2, C18.2, C19.2, C20.2, C21.2, C22.2, C23.2, C24.2, C25.2, C28.2, C29.2, C30.2, C31.2, C32.2, C33.2, C34.2, C35.2, C36.1, C37.2, C38.2, C39.2, C40.2, D1.2 (A2), D2.2 (A2), D3.1 (K), D4.1 (K), D5.1 (K), D6.1 (K), D7.3, D8.1 (K), D9.1 (K), D10.1 (K), J1.3, J2.S1, J3.3, J4.2, J5.2, J6.1, J6.3, J6.5, J7.1, J7.3, J7.5, J8.2, J9.2, J10.2, J11.2, J12.1, J12.3, J12.5, J13.1, J13.3, J13.5, J14.2, J15.2, J16.1, J16.3, J16.5, J17.2, J18.1, J19.2, J20.1, J20.3, J20.5, J21.2, J22.2, J24.3, J24.4, L1.3, Q2.2 (S), Q3.2 (S), R12.2, R15.2, R17.2, R18.2, R22.2, R26.2, R29.1, R34.2, R35.2, R36.1, R38.2, R42.2, R51.2, R56.2, S1.3, U1.8 (GND), U2.3 (GND), U3.3 (AGND), U3.9 (PGND), U5.5 (GND), U6.2 (GND), U6.8 (STB), U7.2 (GND)
LIM1 D30: A1.D30, C9.1, R30.2, R59.2
LIM2 D31: A1.D31, C15.1, R27.2, R58.2
LIM3 D32: A1.D32, C18.1, R25.2, R57.2
LIM4 D33: A1.D33, C24.1, R21.2, R53.2
LIM5 D34: A1.D34, C23.1, R23.2, R52.2
LIM6 D35: A1.D35, C21.1, R24.2, R47.2
MOTION_ALLOWED PIN#2: A1.D2, R22.1, U2.2 (B)
unnamed: A1.D14 (A0), R3.1
unnamed: A1.D15 (A1), R6.1
unnamed: A1.D16 (A2), R4.1
unnamed: A1.D17 (A3), R7.1
unnamed: A1.D18 (A4), R5.1
unnamed: A1.D19 (A5), R13.1
unnamed: A1.D24 (A10), R9.1
unnamed: A1.D25 (A11), R2.1
unnamed: A1.D26 (A12), R8.1
unnamed: A1.D27 (A13), R1.1
unnamed: A1.D28, R19.2
unnamed: A1.D29, R20.2
unnamed: C5.1, R15.1
unnamed: C7.2, R16.2, R18.1
unnamed: C25.1, R41.2
unnamed: C26.2, L2.1
unnamed: C27.1, R43.1
unnamed: C7.1, C8.1, C11.1, C13.1, C16.1, D2.1 (A1), Q1.2 (S), R33.1, U3.8 (VIN)
unnamed: D4.2 (A), J4.1, J5.1, R47.1
unnamed: D5.2 (A), J8.1, J9.1, R52.1
unnamed: D6.2 (A), J10.1, J11.1, R53.1
unnamed: D8.2 (A), J14.1, J15.1, R57.1
unnamed: D9.2 (A), J17.1, J19.1, R58.1
unnamed: D10.2 (A), J21.1, J22.1, R59.1
unnamed: C4.2, D11.2 (A), Q1.1 (G), R16.1
unnamed: J1.2, L1.2
unnamed: J3.1, JP1.2 (B), R49.2, S1.1
unnamed: J3.2, R48.1, R50.2, S1.2
unnamed: F3.3, J18.2
unnamed: F2.3, J18.3
unnamed: JP1.1 (A), R48.2
unnamed: JP2.1 (A), R55.1
unnamed: D7.2, F2.1, JP2.2 (B), R54.2, U5.6 (A)
unnamed: Q2.1 (G), R36.2, R37.1
unnamed: C20.1, Q3.1 (G), R32.1, R35.1
unnamed: R43.2, R44.2, R45.1
unnamed: R10.2, R11.1, U1.1 (EN_UVLO)
unnamed: R26.1, U1.9 (ILM)
unnamed: C3.1, U1.10 (ITIMER)
unnamed: R11.2, R12.1, U1.2 (OVLO)
unnamed: R28.1, R29.2, U1.4 (PGTH)
unnamed: C5.2, U1.7 (dVdt)
unnamed: R40.1, U3.7 (BOOT)
unnamed: R38.1, U3.10 (MODE)
unnamed: R41.1, U3.4 (PG)
unnamed: C22.1, U3.5 (SS)
unnamed: D7.1, F3.1, R55.2, R56.1, U5.7 (B)
unnamed: R49.1, U6.7 (CANH)
unnamed: R50.1, U6.6 (CANL)
unnamed: R46.2, U7.3 (EN)
RS485_DE D6: A1.D6, R51.1, U5.2 (~RE), U5.3 (DE)
RS485_RX D9: A1.D9, U5.1 (RO)
RS485_TX D10: A1.D10 ((CS)D10), U5.4 (DI)
Step1 D14: J7.2, R3.2
Step2 D15: J12.2, R6.2
Step3 D16: J16.2, R4.2
Step4 D17: J6.2, R7.2
Step5 D18: J13.2, R5.2
Step6 D19: J20.2, R13.2

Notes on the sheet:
The CAN interface is implemented using a TCAN1042 transceiver with proper 3.3 V I/O, ESD protection, selectable 120 Ω termination via jumper, and a standard CANH/CANL/GND connector for reliable differential communication. Connect the Jetson to CAN only through a USB-to-CAN adapter, wiring its CANH 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
5 VDC input from TPS56A37RPAR buck converter output, VOUT (TPS259474 OUT): Protected 5 VDC rail feeding Jetson Nano Dev Kit 5 V input (J41 pins 2 & 4) PG ---> Teensy 4.1 GPIO input
6 Limit sensors terminals
Keep 100 kΩ pull-up from EN to +5V_LOGIC (post-ferrite, same node as IN), ensuring always-on operation while allowing future EN control if needed.
For the BigTreeTech TMC2209 with a 7-pin logic connector, connect VM to +24V motor supply*, both GND pins to system ground, VDD to 3.3V_LOGIC, STEP to the Teensy STEPx pin, DIR to the Teensy DIRx pin, and EN to GLOBAL_EN_N (active-low); leave MS1, MS2, PDN/UART, CLK, and DIAG unconnected unless use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
E-Stop(A22NZ-MNM-NGA1) with Deadman stop withRC filter. GLOBAL_ENABLE is hardware-enforced via an active-LOW MOSFET gate; drivers are disabled unless E-STOP (NC), DEADMAN (NO), and MCU MOTION_ALLOW are all asserted, ensuring fail-safe shutdown independent of firmware state.
RS-485 half-duplex interface with optional termination jumper, failsafe biasing, surge protection, and MCU-controlled direction.
For Notes:

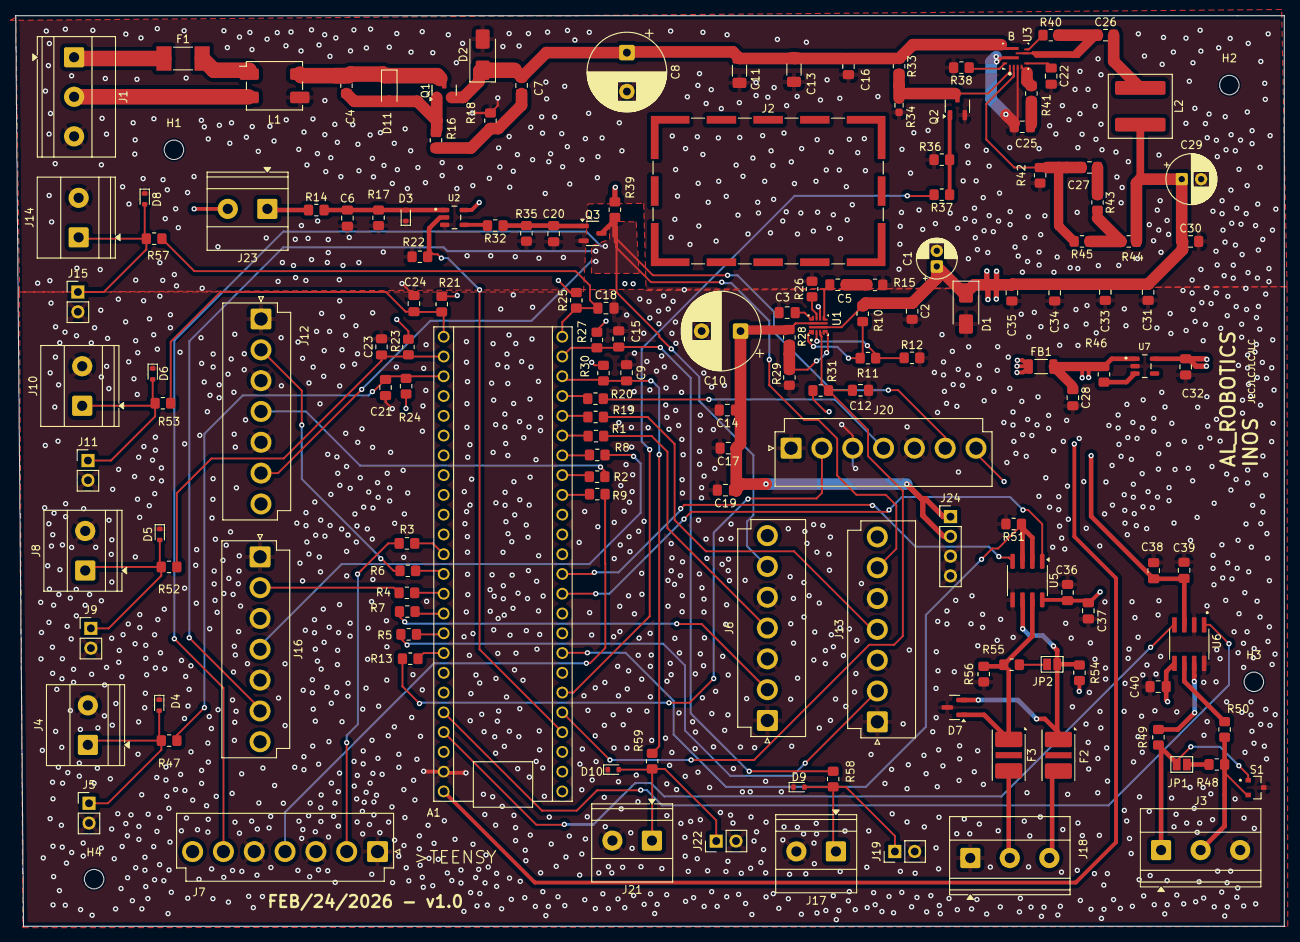
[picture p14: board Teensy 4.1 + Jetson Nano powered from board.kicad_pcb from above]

Board: 4 copper layers, 163.0 x 117.0 mm, 157 parts (0 on the bottom side), 91 nets.

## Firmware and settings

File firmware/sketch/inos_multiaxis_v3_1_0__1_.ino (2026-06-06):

#include <FlexCAN_T4.h>
#include <math.h>

FlexCAN_T4<CAN1, RX_SIZE_256, TX_SIZE_16> Can0;

// ======================================================
// CAN IDs
// ======================================================

constexpr uint16_t ID_JETSON_HEARTBEAT = 0x100;
constexpr uint16_t ID_MOTION_COMMAND   = 0x110;
constexpr uint16_t ID_ENABLE_COMMAND   = 0x120;
constexpr uint16_t ID_POSITION_COMMAND = 0x130;
constexpr uint16_t ID_STOP_COMMAND     = 0x140;
constexpr uint16_t ID_HOME_COMMAND     = 0x150;

constexpr uint16_t ID_INOS_HEARTBEAT   = 0x200;
constexpr uint16_t ID_INOS_STATUS      = 0x210;
constexpr uint16_t ID_INOS_POSITION    = 0x220;   // NEW: position report frame
constexpr uint16_t ID_INOS_FAULT       = 0x230;

// ======================================================
// STATES
// ======================================================

enum BoardState : uint8_t {
  STATE_BOOT    = 0,
  STATE_IDLE    = 1,
  STATE_ENABLED = 2,
  STATE_MOVING  = 3,
  STATE_HOMING  = 4,
  STATE_FAULT   = 5
};

enum FaultCode : uint8_t {
  FAULT_NONE               = 0,
  FAULT_HEARTBEAT_TIMEOUT  = 1,
  FAULT_LIMIT_HIT          = 2,
  FAULT_ESTOP_ACTIVE       = 3,
  FAULT_DRIVER_DISABLED    = 4,
  FAULT_HOMING_FAILED      = 5,
  FAULT_UNKNOWN_COMMAND    = 6,
  FAULT_AXIS_BUSY          = 7,
  FAULT_HOME_NOT_SUPPORTED = 8
};

enum MotionMode : uint8_t {
  MODE_IDLE     = 0,
  MODE_VELOCITY = 1,
  MODE_POSITION = 2,
  MODE_HOMING   = 3
};

// ======================================================
// HARDWARE PIN MAP
// Axis numbering: 1–6 (index 0 unused throughout)
// ======================================================

constexpr uint8_t AXIS_COUNT = 6;

constexpr int LED_PIN        = 13;
constexpr int MOTION_ALLOWED = 2;    // GLOBAL_EN_N control

constexpr int STEP_PINS[AXIS_COUNT + 1] = {
  -1,
  14,   // Axis 1 / J7  / STEP D14
  16,   // Axis 2 / J16 / STEP D16
  15,   // Axis 3 / J12 / STEP D15
  17,   // Axis 4 / J6  / STEP D17
  18,   // Axis 5 / J13 / STEP D18
  19    // Axis 6 / J20 / STEP D19
};

constexpr int DIR_PINS[AXIS_COUNT + 1] = {
  -1,
  24,   // Axis 1 / J7  / DIR D24
  26,   // Axis 2 / J16 / DIR D26
  25,   // Axis 3 / J12 / DIR D25
  27,   // Axis 4 / J6  / DIR D27
  28,   // Axis 5 / J13 / DIR D28
  29    // Axis 6 / J20 / DIR D29
};

constexpr int SENSOR_PINS[AXIS_COUNT + 1] = {
  -1,
  34,   // Axis 1 / J8  / LIM5 D34
  32,   // Axis 2 / J14 / LIM3 D32
  33,   // Axis 3 / J10 / LIM4 D33
  30,   // Axis 4 / J21 / LIM1 D30
  35,   // Axis 5 / J4  / LIM6 D35
  -1    // Axis 6 / no sensor yet
};

// Confirmed homing directions
constexpr uint8_t HOME_DIR[AXIS_COUNT + 1] = {
  0,
  0,    // Axis 1
  1,    // Axis 2
  0,    // Axis 3
  0,    // Axis 4
  0,    // Axis 5
  0     // Axis 6 unused
};

constexpr bool AXIS_HAS_SENSOR[AXIS_COUNT + 1] = {
  false,
  true,   // Axis 1
  true,   // Axis 2
  true,   // Axis 3
  true,   // Axis 4
  true,   // Axis 5
  false   // Axis 6 — no sensor installed yet
};

// Proximity adapter: no metal = LOW, screw/metal detected = HIGH
constexpr bool SENSOR_ACTIVE_LEVEL = HIGH;

// ======================================================
// SYSTEM SETTINGS
// ======================================================

constexpr uint32_t CAN_BAUDRATE                = 500000;
constexpr uint32_t HEARTBEAT_TIMEOUT_MS        = 500;
constexpr uint32_t TX_HEARTBEAT_PERIOD_MS      = 100;
constexpr uint32_t TX_STATUS_PERIOD_MS         = 200;
constexpr uint32_t TX_POSITION_PERIOD_MS       = 200;   // NEW: position report cadence
constexpr uint16_t MAX_ALLOWED_SPEED_STEPS_SEC = 1000;

constexpr float    ACCEL_STEPS_PER_SEC2        = 300.0f;
constexpr uint32_t RAMP_UPDATE_MS              = 10;

// Minimum speed floor in position mode.
// Prevents stall near target but causes up to ~1-step overshoot at low speed.
// Acceptable for current bring-up; revisit when precise positioning is needed.
constexpr float POSITION_MIN_SPEED = 20.0f;

// ======================================================
// FORWARD DECLARATIONS
// Needed because setFault / startMotion reference functions
// defined later in the file.
// ======================================================

void sendFault(FaultCode code);
void applyEnableState();
void stopMotionOutput();

// ======================================================
// GLOBAL STATE
// ======================================================

bool jetsonAlive     = false;
bool systemEnabled   = false;
bool motionCommanded = false;
bool faultActive     = false;

BoardState currentState = STATE_BOOT;
FaultCode  currentFault = FAULT_NONE;
MotionMode motionMode   = MODE_IDLE;

uint8_t activeAxis      = 0;
uint8_t lastAxisCommand = 0;
uint8_t dirCommand      = 0;

uint16_t targetSpeed  = 0;
float    currentSpeed = 0.0f;

// Per-axis position counters (steps from home, signed)
int32_t currentPositionSteps[AXIS_COUNT + 1] = {0};

uint32_t remainingSteps = 0;
uint32_t commandedSteps = 0;

bool          stepOutputState  = false;
elapsedMicros stepTimer;
uint32_t      stepHalfPeriodUs = 0;

elapsedMillis heartbeatTimer;
elapsedMillis txHeartbeatTimer;
elapsedMillis txStatusTimer;
elapsedMillis txPositionTimer;   // NEW
elapsedMillis rampTimer;

uint8_t heartbeatCounter = 0;
uint8_t statusCounter    = 0;
uint8_t positionCounter  = 0;   // NEW

// NEW: tracks which axis to report position for in the rotating report
uint8_t positionReportAxis = 1;

// ======================================================
// HELPERS
// ======================================================

bool validAxis(uint8_t axis) {
  return axis >= 1 && axis <= AXIS_COUNT;
}

bool sensorActive(uint8_t axis) {
  if (!validAxis(axis))          return false;
  if (!AXIS_HAS_SENSOR[axis])    return false;
  return digitalRead(SENSOR_PINS[axis]) == SENSOR_ACTIVE_LEVEL;
}

uint8_t readSensorBitmask() {
  uint8_t bits = 0;
  for (uint8_t axis = 1; axis <= AXIS_COUNT; axis++) {
    if (AXIS_HAS_SENSOR[axis] && sensorActive(axis)) {
      bits |= (1 << (axis - 1));
    }
  }
  return bits;
}

// Force all STEP pins LOW except the active axis.
// GLOBAL_EN_N enables every connected TMC2209 simultaneously,
// so any floating STEP pin can cause unintended movement.
void lockInactiveAxes() {
  for (uint8_t axis = 1; axis <= AXIS_COUNT; axis++) {
    if (axis != activeAxis) {
      digitalWrite(STEP_PINS[axis], LOW);
    }
  }
}

void updateStepTimingFromCurrentSpeed() {
  if (currentSpeed <= 0.5f || activeAxis == 0) {
    stepHalfPeriodUs = 0;
    stepOutputState  = false;
    if (validAxis(activeAxis)) {
      digitalWrite(STEP_PINS[activeAxis], LOW);
    }
    return;
  }

  uint32_t fullPeriodUs = (uint32_t)(1000000.0f / currentSpeed);
  if (fullPeriodUs < 2) fullPeriodUs = 2;

  stepHalfPeriodUs = fullPeriodUs / 2;
  if (stepHalfPeriodUs < 1) stepHalfPeriodUs = 1;
}

// ======================================================
// MOTION STOP / FAULT / ENABLE
// ======================================================

void stopMotionOutput() {
  if (validAxis(activeAxis)) {
    digitalWrite(STEP_PINS[activeAxis], LOW);
  }

  motionCommanded  = false;
  motionMode       = MODE_IDLE;
  targetSpeed      = 0;
  currentSpeed     = 0.0f;
  stepHalfPeriodUs = 0;
  stepOutputState  = false;
  remainingSteps   = 0;
  commandedSteps   = 0;
  activeAxis       = 0;

  lockInactiveAxes();

  if      (faultActive)                        currentState = STATE_FAULT;
  else if (systemEnabled && jetsonAlive)        currentState = STATE_ENABLED;
  else                                          currentState = STATE_IDLE;
}

void setFault(FaultCode code) {
  faultActive    = true;
  currentFault   = code;
  currentState   = STATE_FAULT;
  systemEnabled  = false;

  stopMotionOutput();
  digitalWrite(MOTION_ALLOWED, LOW);

  Serial.print("FAULT SET: ");
  Serial.println((uint8_t)code);
}

void clearFault() {
  faultActive   = false;
  currentFault  = FAULT_NONE;
  systemEnabled = false;

  stopMotionOutput();
  digitalWrite(MOTION_ALLOWED, LOW);
  currentState = STATE_IDLE;

  Serial.println("FAULT CLEARED");
}

void applyEnableState() {
  if (systemEnabled && jetsonAlive && !faultActive) {
    digitalWrite(MOTION_ALLOWED, HIGH);

    if      (motionMode == MODE_HOMING && motionCommanded) currentState = STATE_HOMING;
    else if (motionCommanded && currentSpeed > 0.5f)       currentState = STATE_MOVING;
    else                                                   currentState = STATE_ENABLED;
  } else {
    digitalWrite(MOTION_ALLOWED, LOW);
    stopMotionOutput();
    if (!faultActive) currentState = STATE_IDLE;
  }
}

// ======================================================
// POSITION RAMP HELPER
// ======================================================

float computePositionDesiredSpeed(uint32_t stepsLeft) {
  float distance      = (float)stepsLeft;
  float maxSafeSpeed  = sqrtf(2.0f * ACCEL_STEPS_PER_SEC2 * distance);
  float commandedMax  = (float)targetSpeed;
  return (maxSafeSpeed < commandedMax) ? maxSafeSpeed : commandedMax;
}

// ======================================================
// MOTION START
// ======================================================

void startMotion(uint8_t axis, MotionMode mode, uint8_t dir, uint16_t speed, uint32_t steps) {
  if (!validAxis(axis)) {
    sendFault(FAULT_UNKNOWN_COMMAND);
    return;
  }

  if (activeAxis != 0 && activeAxis != axis) {
    Serial.println("Command ignored: another axis already active");
    sendFault(FAULT_AXIS_BUSY);
    return;
  }

  if (!jetsonAlive || faultActive || !systemEnabled) {
    Serial.println("Motion ignored: heartbeat missing, fault active, or system disabled");
    return;
  }

  if (speed > MAX_ALLOWED_SPEED_STEPS_SEC) speed = MAX_ALLOWED_SPEED_STEPS_SEC;

  if (speed == 0) {
    stopMotionOutput();
    applyEnableState();
    return;
  }

  activeAxis      = axis;
  lastAxisCommand = axis;
  dirCommand      = dir ? 1 : 0;

  digitalWrite(DIR_PINS[axis], dirCommand ? HIGH : LOW);

  motionMode       = mode;
  motionCommanded  = true;
  targetSpeed      = speed;
  currentSpeed     = 0.0f;
  stepHalfPeriodUs = 0;
  stepOutputState  = false;
  stepTimer        = 0;

  if (mode == MODE_POSITION) {
    remainingSteps = steps;
    commandedSteps = steps;
  } else {
    remainingSteps = 0;
    commandedSteps = 0;
  }

  digitalWrite(STEP_PINS[axis], LOW);
  lockInactiveAxes();
  applyEnableState();
}

// ======================================================
// SPEED RAMP UPDATE
// ======================================================

void updateSpeedRamp() {
  if (rampTimer < RAMP_UPDATE_MS) return;

  float dt = (float)rampTimer / 1000.0f;
  rampTimer = 0;

  float speedDelta = ACCEL_STEPS_PER_SEC2 * dt;

  if (!systemEnabled || !jetsonAlive || faultActive || !motionCommanded || activeAxis == 0) {
    currentSpeed = (currentSpeed > speedDelta) ? currentSpeed - speedDelta : 0.0f;
    updateStepTimingFromCurrentSpeed();
    return;
  }

  float desiredSpeed = 0.0f;

  if (motionMode == MODE_VELOCITY || motionMode == MODE_HOMING) {
    desiredSpeed = (float)targetSpeed;

  } else if (motionMode == MODE_POSITION) {
    if (remainingSteps == 0) {
      stopMotionOutput();
      updateStepTimingFromCurrentSpeed();
      return;
    }

    desiredSpeed = computePositionDesiredSpeed(remainingSteps);

    // Floor prevents stall near target.
    // NOTE: causes up to ~1-step overshoot. Revisit for precision positioning.
    if (desiredSpeed < POSITION_MIN_SPEED) {
      desiredSpeed = POSITION_MIN_SPEED;
      if (desiredSpeed > (float)targetSpeed) desiredSpeed = (float)targetSpeed;
    }
  }

  if      (currentSpeed < desiredSpeed) { currentSpeed += speedDelta; if (currentSpeed > desiredSpeed) currentSpeed = desiredSpeed; }
  else if (currentSpeed > desiredSpeed) { currentSpeed -= speedDelta; if (currentSpeed < desiredSpeed) currentSpeed = desiredSpeed; }

  updateStepTimingFromCurrentSpeed();

  if      (motionMode == MODE_HOMING && motionCommanded)  currentState = STATE_HOMING;
  else if (motionCommanded && currentSpeed > 0.5f)        currentState = STATE_MOVING;
  else if (systemEnabled && jetsonAlive && !faultActive)  currentState = STATE_ENABLED;
}

// ======================================================
// STEP GENERATOR
// ======================================================

void runMotionGenerator() {
  if (!motionCommanded)        return;
  if (!systemEnabled)          return;
  if (faultActive)             return;
  if (!jetsonAlive)            return;
  if (!validAxis(activeAxis))  return;
  if (stepHalfPeriodUs == 0)   return;

  if (stepTimer >= stepHalfPeriodUs) {
    stepTimer      = 0;
    stepOutputState = !stepOutputState;

    digitalWrite(STEP_PINS[activeAxis], stepOutputState);

    if (stepOutputState) {
      // Update signed position counter.
      // dirCommand=1 → positive direction, dirCommand=0 → negative.
      // Physical sign convention should be verified per axis after homing.
      if (dirCommand) currentPositionSteps[activeAxis]++;
      else            currentPositionSteps[activeAxis]--;

      if (motionMode == MODE_POSITION) {
        if (remainingSteps > 0) remainingSteps--;

        if (remainingSteps == 0) {
          stopMotionOutput();
          applyEnableState();
        }
      }
    }
  }
}

// ======================================================
// LIMIT / HOMING INPUT CHECK
// ======================================================

void checkLimitInputs() {
  if (!motionCommanded)              return;
  if (motionMode != MODE_HOMING)     return;
  if (!validAxis(activeAxis))        return;
  if (!AXIS_HAS_SENSOR[activeAxis])  return;

  if (sensorActive(activeAxis)) {
    Serial.print("AXIS ");
    Serial.print(activeAxis);
    Serial.println(" SENSOR ACTIVE -> homing complete, position zeroed");

    currentPositionSteps[activeAxis] = 0;
    stopMotionOutput();
    applyEnableState();
  }
}

// ======================================================
// LED BLINKER
// ======================================================

void blinkLed() {
  static uint32_t lastBlink = 0;
  static bool     ledState  = false;

  uint32_t interval = 600;
  if      (faultActive)                          interval = 100;
  else if (!jetsonAlive)                         interval = 300;
  else if (currentState == STATE_HOMING)         interval = 150;
  else if (systemEnabled)                        interval = 1000;

  if (millis() - lastBlink >= interval) {
    lastBlink = millis();
    ledState  = !ledState;
    digitalWrite(LED_PIN, ledState);
  }
}

// ======================================================
// CAN TX
// ======================================================

void sendHeartbeat() {
  CAN_message_t msg;
  msg.id     = ID_INOS_HEARTBEAT;
  msg.len    = 8;
  msg.buf[0] = heartbeatCounter++;
  msg.buf[1] = (uint8_t)currentState;
  msg.buf[2] = faultActive     ? 1 : 0;
  msg.buf[3] = systemEnabled   ? 1 : 0;
  msg.buf[4] = jetsonAlive     ? 1 : 0;
  msg.buf[5] = activeAxis;
  msg.buf[6] = (uint8_t)currentFault;
  msg.buf[7] = (uint8_t)motionMode;
  Can0.write(msg);
}

void sendStatus() {
  CAN_message_t msg;
  msg.id     = ID_INOS_STATUS;
  msg.len    = 8;

  uint16_t speedInt = (uint16_t)currentSpeed;

  msg.buf[0] = readSensorBitmask();
  msg.buf[1] = (uint8_t)motionMode;
  msg.buf[2] = systemEnabled ? 1 : 0;
  msg.buf[3] = activeAxis;
  msg.buf[4] = (uint8_t)(speedInt & 0xFF);
  msg.buf[5] = (uint8_t)((speedInt >> 8) & 0xFF);
  msg.buf[6] = motionCommanded ? 1 : 0;
  msg.buf[7] = statusCounter++;
  Can0.write(msg);
}

// NEW: Position report frame — rotates through axes one per TX period.
// Frame 0x220 layout:
//   buf[0]   axis number (1–6)
//   buf[1]   counter
//   buf[4:7] currentPositionSteps[axis] as int32 little-endian
//
// Report current axis FIRST, then advance — ensures Axis 1 is the
// first frame transmitted rather than being skipped on the first call.
void sendPosition() {
  int32_t pos = currentPositionSteps[positionReportAxis];

  CAN_message_t msg;
  msg.id     = ID_INOS_POSITION;
  msg.len    = 8;
  msg.buf[0] = positionReportAxis;
  msg.buf[1] = positionCounter++;
  msg.buf[2] = 0;
  msg.buf[3] = 0;
  msg.buf[4] = (uint8_t)( pos        & 0xFF);
  msg.buf[5] = (uint8_t)((pos >> 8)  & 0xFF);
  msg.buf[6] = (uint8_t)((pos >> 16) & 0xFF);
  msg.buf[7] = (uint8_t)((pos >> 24) & 0xFF);
  Can0.write(msg);

  // Advance after sending so next call reports the next axis
  positionReportAxis++;
  if (positionReportAxis > AXIS_COUNT) positionReportAxis = 1;
}

void sendFault(FaultCode code) {
  CAN_message_t msg;
  msg.id     = ID_INOS_FAULT;
  msg.len    = 8;
  msg.buf[0] = (uint8_t)code;
  msg.buf[1] = lastAxisCommand;
  msg.buf[2] = activeAxis;
  msg.buf[3] = (uint8_t)motionMode;
  msg.buf[4] = 0;
  msg.buf[5] = 0;
  msg.buf[6] = 0;
  msg.buf[7] = 0;
  Can0.write(msg);
}

// ======================================================
// CAN RX HANDLERS
// ======================================================

void processHeartbeat(const CAN_message_t &msg) {
  heartbeatTimer = 0;

  if (faultActive && currentFault == FAULT_HEARTBEAT_TIMEOUT) {
    clearFault();
  }

  jetsonAlive = true;

  if (!faultActive) {
    currentState = systemEnabled ? STATE_ENABLED : STATE_IDLE;
  }
}

void processEnable(const CAN_message_t &msg) {
  uint8_t enableValue = msg.buf[0];

  Serial.print("ENABLE CMD RX: ");
  Serial.println(enableValue);

  if (enableValue == 1) {
    if (!faultActive && jetsonAlive) {
      systemEnabled = true;
    } else {
      Serial.println("Enable ignored: fault active or heartbeat missing");
    }
  } else {
    systemEnabled = false;
    stopMotionOutput();
  }

  applyEnableState();
}

void processMotion(const CAN_message_t &msg) {
  uint8_t  axis           = msg.buf[0];
  uint8_t  enable         = msg.buf[1];
  uint8_t  dir            = msg.buf[2];
  uint16_t requestedSpeed = ((uint16_t)msg.buf[5] << 8) | msg.buf[4];

  lastAxisCommand = axis;

  Serial.print("VELOCITY CMD RX axis=");
  Serial.print(axis);
  Serial.print(" enable=");
  Serial.print(enable);
  Serial.print(" dir=");
  Serial.print(dir);
  Serial.print(" speed=");
  Serial.println(requestedSpeed);

  if (!validAxis(axis)) {
    sendFault(FAULT_UNKNOWN_COMMAND);
    return;
  }

  if (enable == 0 || requestedSpeed == 0) {
    if (axis == activeAxis || activeAxis == 0) {
      stopMotionOutput();
      applyEnableState();
    }
    return;
  }

  startMotion(axis, MODE_VELOCITY, dir, requestedSpeed, 0);
}

void processPosition(const CAN_message_t &msg) {
  uint8_t  axis           = msg.buf[0];
  uint8_t  dir            = msg.buf[1];
  uint16_t requestedSpeed = ((uint16_t)msg.buf[3] << 8) | msg.buf[2];
  uint32_t steps =
    ((uint32_t)msg.buf[7] << 24) |
    ((uint32_t)msg.buf[6] << 16) |
    ((uint32_t)msg.buf[5] << 8)  |
    ((uint32_t)msg.buf[4]);

  lastAxisCommand = axis;

  Serial.print("POSITION CMD RX axis=");
  Serial.print(axis);
  Serial.print(" dir=");
  Serial.print(dir);
  Serial.print(" speed=");
  Serial.print(requestedSpeed);
  Serial.print(" steps=");
  Serial.println(steps);

  if (!validAxis(axis)) {
    sendFault(FAULT_UNKNOWN_COMMAND);
    return;
  }

  // FIXED: was silent drop. Now logs and sends fault for clarity.
  if (steps == 0) {
    Serial.print("POSITION CMD axis=");
    Serial.print(axis);
    Serial.println(" ignored: steps=0");
    sendFault(FAULT_UNKNOWN_COMMAND);
    return;
  }

  if (requestedSpeed == 0) {
    Serial.println("POSITION CMD ignored: speed=0");
    return;
  }

  startMotion(axis, MODE_POSITION, dir, requestedSpeed, steps);
}

void processHome(const CAN_message_t &msg) {
  uint8_t  axis           = msg.buf[0];
  uint8_t  dir            = msg.buf[1];
  uint16_t requestedSpeed = ((uint16_t)msg.buf[3] << 8) | msg.buf[2];

  lastAxisCommand = axis;

  Serial.print("HOME CMD RX axis=");
  Serial.print(axis);
  Serial.print(" dir=");
  Serial.print(dir);
  Serial.print(" speed=");
  Serial.println(requestedSpeed);

  if (!validAxis(axis)) {
    sendFault(FAULT_UNKNOWN_COMMAND);
    return;
  }

  if (!AXIS_HAS_SENSOR[axis]) {
    Serial.print("HOME CMD axis=");
    Serial.print(axis);
    Serial.println(" ignored: no sensor installed → FAULT_HOME_NOT_SUPPORTED");
    sendFault(FAULT_HOME_NOT_SUPPORTED);
    return;
  }

  if (activeAxis != 0 && activeAxis != axis) {
    Serial.println("HOME CMD ignored: another axis already active");
    sendFault(FAULT_AXIS_BUSY);
    return;
  }

  if (sensorActive(axis)) {
    Serial.print("Axis ");
    Serial.print(axis);
    Serial.println(" sensor already active — position set to zero, no motion needed");
    currentPositionSteps[axis] = 0;
    stopMotionOutput();
    applyEnableState();
    return;
  }

  if (requestedSpeed == 0) requestedSpeed = 100;
  if (requestedSpeed > 500) requestedSpeed = 500;

  // Use the firmware-confirmed homing direction, not the CAN-supplied dir.
  // HOME_DIR[] was validated physically per axis — trusting it prevents
  // a wrong-direction home if the sender passes an incorrect dir byte.
  startMotion(axis, MODE_HOMING, HOME_DIR[axis], requestedSpeed, 0);
}

void processStop(const CAN_message_t &msg) {
  Serial.println("STOP CMD RX");
  stopMotionOutput();
  applyEnableState();
}

// ======================================================
// CAN RX DISPATCHER
// ======================================================
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
void loop() {
  lockInactiveAxes();      // Safety: keep unused STEP pins LOW every loop

  readCanMessages();
  checkHeartbeatTimeout();
  checkLimitInputs();
  updateSpeedRamp();
  runMotionGenerator();
  blinkLed();

  if (txHeartbeatTimer >= TX_HEARTBEAT_PERIOD_MS) {
    txHeartbeatTimer = 0;
    sendHeartbeat();
  }

  if (txStatusTimer >= TX_STATUS_PERIOD_MS) {
    txStatusTimer = 0;
    sendStatus();
  }

  // NEW: rotating per-axis position report
  if (txPositionTimer >= TX_POSITION_PERIOD_MS) {
    txPositionTimer = 0;
    sendPosition();
  }
}

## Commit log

2026-06-06 Enhance README with project details and features
    Expanded the README to include detailed project description, key features, system architecture, design philosophy, current status, and project goals.
2026-06-06 Revise README for clarity and detail enhancement
    Expanded project overview and clarified responsibilities of NVIDIA Jetson and INOS controller. Updated hardware features and current status sections for better clarity.
2026-06-06 Update section title for controller board
2026-06-08 Update image for INOS Rev A Board Bottom
2026-06-11 Add files via upload
    Added INOS Rev B schematic PDF.
    Rev B documents the updated robotic arm controller design, including:
    - 24V protected system input
    - 19V Jetson Orin Nano Developer Kit power output
    - 24V to 5V logic buck section
    - 5V / 3.3V logic rails
    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
2026-06-28 Remove PCB Layout section from README
    Removed PCB Layout section and its image from README.
